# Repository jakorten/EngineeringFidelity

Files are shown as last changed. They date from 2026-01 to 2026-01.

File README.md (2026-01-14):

# Engineering Fidelity of CPR Training Manikins

A research paper for **Measurement Science and Technology** (IOP Publishing) - Focus Collection on *"Data-Centric Exploration and Explanation of Physical and Engineering Phenomena"*

**Deadline:** March 31, 2026

**Invitation:** Personal recommendation by Guest Editor Rui Yuan (Wuhan University of Science and Technology)

**Collection page:** https://iopscience.iop.org/collections/mst-251119-1003

## Overview

This paper develops a data-driven reference model for CPR training manikin characterization, combining chest compression and ventilation mechanics.

### Core Concept

```
Human Reference Model    →    Manikin Characterization    →    Fidelity Gap Analysis
(from medical literature)      (empirical testing)              (model vs. reality)
```

1. Build a human reference model from medical/clinical literature
2. Systematically test multiple CPR manikins against this reference
3. Quantify the "engineering fidelity gap" for each manikin

## Key Contributions

- First systematic benchmark combining compression AND ventilation fidelity
- Data-driven reference model synthesized from published clinical datasets
- Quantified engineering fidelity index for manikin procurement decisions
- Novel ventilation fidelity analysis (largely unstudied area)

## Engineering Fidelity Index (EFI)

The EFI is a quantified metric to score how well a manikin replicates human biomechanics:

```
EFI = w_c * F_compression + w_v * F_ventilation
```

| Component | Description |
|---|---|
| F_compression | Normalized score for stiffness + damping within human envelope |
| F_ventilation | Normalized score for compliance + resistance within human envelope |
| w_c, w_v | Weighting factors (adjustable based on training priorities) |

**Scoring:**
- **EFI = 1.0** - Perfect match to human reference center
- **EFI = 0.0** - Deviation equals full envelope width

Higher EFI = more physiologically realistic manikin. This provides training centers a single number to compare manikins for procurement decisions.

## Paper Structure

1. **Introduction** - Engineering fidelity concept and research gap
2. **Human Reference Model** - Compression and ventilation mechanics from literature
3. **Uncertainty Envelope** - Acceptable range from human variability
4. **Manikin Characterization Protocol** - Standardized testing methodology
5. **Results** - Fidelity comparison across multiple manikins
6. **Engineering Fidelity Index** - Quantified metric proposal
7. **Discussion & Conclusion**

## Related Work

| Paper | Venue | Relationship |
|---|---|---|
| Sensor validation | IEEE TIM | Methodology foundation |
| TEF RCT | IEEE THMS | Training effectiveness evidence |
| [Perspective paper](https://github.com/jakorten/Proposition.git) | Resuscitation | Conceptual framework |
| **This paper** | MST | Technical methodology + data |

The perspective paper argues *for* engineering fidelity; this paper provides the *tools to measure* it.

## Current Status

| Section | Status |
|---|---|
| 1. Introduction | Draft complete |
| 2. Human Reference Model | Draft complete |
| 3. Uncertainty Envelope | Draft complete |
| 4. Manikin Characterization Protocol | Draft complete |
| 5. Results | Awaiting data collection |
| 6. Engineering Fidelity Index | Draft complete |
| 7. Discussion | Draft complete |
| 8. Conclusion | Draft complete |

**Next steps:** Data collection (target: mid-February 2026)

## Repository Structure

```
├── MST_paper_outline.md          # Detailed paper outline
├── MST_paper_supervisor_summary.md  # Executive summary for supervisors
├── CLAUDE.md                     # AI assistant guidance
└── working/
    ├── paper_draft.md            # Current paper draft (~4,750 words)
    ├── literature_review.md      # Comprehensive literature synthesis
    ├── apparatus_expansion.md    # Hardware requirements for manikin testing
    ├── data_collection_checklist.md  # Testing protocol checklist
    ├── articles/                 # Converted reference papers (markdown)
    ├── datasheets/               # Bronkhorst MFM documentation
    │   ├── 6264-ff-m11-en-datasheet.md
    │   ├── 917158-manual-flexi-flow-compact.md
    │   └── N0551_N2510646_A_m.md
    └── scripts/
        └── ventilation_mechanics.py  # C/R calculation module
```

## Key References

### Compression Mechanics
- Tomlinson AE et al. (2007). *Resuscitation*. 72(3):364-370.
- Ruiz de Gauna S et al. (2023). *Comput Methods Programs Biomed*. 242:107847.
- Lim H et al. (2024). *IEEE J Transl Eng Health Med*. 12:542-549.

### Ventilation Mechanics
- Huang J et al. (2016). *J Thorac Dis*. 8(3):513-519.
- Battisti O et al. (2012). *Pediatr Therapeut*. 2(2):114.

## Author

Jan Korten

## License

All rights reserved. Academic research in progress.

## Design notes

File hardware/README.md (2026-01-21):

# Hardware Components

## Compression Actuator Extension

**File:** `Compression Actuator extension.stl`

**Purpose:** Extension piece mounted on load cell for chest compression testing

**Dimensions:**
| Parameter | Value |
|---|---|
| Contact diameter | ~20 mm |
| Extension height | ~23.3 mm |
| Contact shape | Flat/disc |

**Rationale:**

The 20mm contact diameter matches the **overlapping thumbs technique** recommended in current guidelines:

> *"Use the two-thumb-hands-encircling-technique with overlapping or adjacent thumbs to deliver chest compressions."*
> — ERC Guidelines 2025, Newborn Resuscitation

| Thumb Position | Contact Width | Our Actuator |
|---|---|---|
| Adjacent thumbs | ~30-40 mm | - |
| **Overlapping thumbs** | **~15-20 mm** | **~20 mm ✓** |

**Guidelines references:**
- ERC 2025: Two-thumb-hands-encircling with overlapping or adjacent thumbs
- Lim JS et al.: Comparison of overlapping (OP) and adjacent thumb positions (AP)
- Schmölzer 2023: Mechanical CC device with similar contact design

**Conclusion:** The 20mm actuator is appropriate for characterizing manikin response to the **overlapping thumbs technique** per ERC 2025 guidelines.

**Mounting:**
- Attaches to DYMH-103 load cell
- Load cell mounted on CNC linear actuator (BlackBox X32)

---

## Load Cell

**Model:** DYMH-103
**Range:** 0-5 kg (0-49 N)
**Application:** Infant compression (target force ~14-30 N)

**ADC:** HX711 (Sparkfun, 24-bit)
**MCU:** STM32F405

---

## Reference: Schmölzer 2023 Setup

From O'Reilly/Schmölzer (Pediatric Research, 2024):
- Mechanical CC device with flat contact point
- Target depth: 33% AP chest diameter
- CC rate: 90/min
- Acceleration: 500 cm/s²
- Recoil speed: 50 cm/s

Our actuator design is compatible with this approach.

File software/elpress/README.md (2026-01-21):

# EL-PRESS Pressure Sensor

Bronkhorst EL-PRESS P-502C for airway pressure measurement during manikin ventilation characterization.

## Hardware

| Parameter | Value |
|---|---|
| Model | EL-PRESS P-502C |
| Type | Gauge pressure (relative to atmosphere) |
| Range | 0-100 mbar |
| Interface | RS232 via USB adapter |
| Protocol | PROPAR |

## Connection

| Parameter | Value |
|---|---|
| Port | `/dev/cu.usbserial-AQ00Z5CQ` |
| Node address | 4 |
| Baud rate | 38400 |

## Usage

### Setup
```bash
cd software/elpress
source venv/bin/activate
```

### Read pressure
```bash
# Single reading
python read_elpress.py

# Continuous reading (10 seconds, 100ms interval)
python read_elpress.py -c 10 -i 0.1

# Scan for sensor on different nodes
python read_elpress.py --scan
```

### Tare (zero) the sensor
```bash
# Show current offset
python tare_elpress.py

# Set new tare offset
python tare_elpress.py --tare
```

### Diagnostics
```bash
python diagnose_elpress.py
```

## Calibration Notes

- **Warm-up time:** 30 minutes recommended before measurements
- **Baseline offset:** ~45 mbar observed at rest (use tare to zero)
- **Drift:** ~2 mbar/min during warm-up, stabilizes after warm-up
- **Tare procedure:** Run `tare_elpress.py --tare` after warm-up

## PROPAR Parameters

### Measurement Values

| Param | Name | Example | Description |
|---|---|---|---|
| 8 | fmeasure | 23 | Gauge pressure (mbar) - same as `measure` |
| 153 | delta-p | 1.013 | Atmospheric reference (bar) |
| 250 | (absolute?) | 1006.6 | Possibly absolute pressure (mbar) |

### Device Information

| Param | Name | Example | Description |
|---|---|---|---|
| 1 | serial | SNM15211829B | Serial number string |
| 90 | type | DEPC | Device type (Digital Electronic Pressure Controller) |
| 91 | model | P-502C-350R-RGD-33-V | Full model number |
| 92 | serial_alt | M15211829B | Alternative serial |
| 94 | cal_date | 25,11,2015 | Calibration date |
| 105 | firmware | V1.21d | Firmware version |
| 129 | unit | mbar(g) | Measurement unit |
| 175 | ident | 9 | Device identification (9 = DEPC) |

### Configuration

| Param | Name | Example | Description |
|---|---|---|---|
| 21 | capacity | 200.0 | Capacity setting |
| 25 | fluid | AiR | Configured fluid/gas |
| 139 | full_scale | 100.0 | Full scale range (mbar) |
| 167 | capacity_100 | 100.0 | 100% capacity value |
| 246 | baro_press | 1.013 | Barometer pressure (bar) |

### Setpoint (Controller Mode)

| Param | Name | Example | Description |
|---|---|---|---|
| 9 | fsetpoint | 0 | Flow/pressure setpoint |
| setpoint | - | 0 | Setpoint attribute |

## Files

| File | Purpose |
|---|---|
| `read_elpress.py` | Main reader script |
| `tare_elpress.py` | Tare/zero utility |
| `diagnose_elpress.py` | Diagnostic script |
| `elpress_offset.json` | Stored tare offset (auto-generated) |
| `venv/` | Python virtual environment |
| `propar/` | Local propar library |
| `testing_debug/` | Previous debug scripts (FLEXI-FLOW) |

## Dependencies

```bash
pip install propar pyserial
```

Or use the included venv:
```bash
source venv/bin/activate
```

---

## Sensor Specifications (from device)

| Parameter | Value |
|---|---|
| Model | P-502C-350R-RGD-33-V |
| Type | DEPC (Digital Electronic Pressure Controller) |
| Range | 0-100 mbar (gauge) |
| Unit | mbar(g) |
| Fluid | Air |
| Firmware | V1.21d |
| Factory calibration | 25 Nov 2015 |

## Troubleshooting

### Serial errors (Bad file descriptor)
- USB cable may have disconnected
- Another process may be using the port
- Solution: Reconnect USB, restart script

### No response on any node
- Check power (24V required)
- Check RS232 adapter connection
- Try different baud rates (default 38400)

### Readings drift
- Allow 30 min warm-up
- Re-tare after warm-up
- Check for temperature changes

---

*Last updated: 2026-01-21*

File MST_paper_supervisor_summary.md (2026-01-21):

# MST Paper - Supervisor Summary

**Updated:** January 15, 2026

---

## Paper Overview

**Title:** "Mechanical Fidelity of CPR Training Manikins: A Data-Driven Reference Model for Chest Compression and Ventilation Mechanics"

**Key framing:** Traditional "high-fidelity" = visual realism (looks like an infant). Our approach = mechanical fidelity (responds like an infant). *A manikin may look like an infant without responding like one.*

**Target:** Measurement Science and Technology - Special Issue on *"Data-Centric Exploration and Explanation of Physical and Engineering Phenomena"*

**Deadline:** March 31, 2026 (~2.5 months remaining)

**Link:** https://iopscience.iop.org/collections/mst-251119-1003

---

## Current Progress

### Literature Verification: 69% P0 Complete

| Priority | Verified | Total | Coverage |
|---|---|---|---|
| P0 (Critical) | 9 | 13 | **69%** |
| P1 (Important) | 1 | 7 | 14% |
| P2 (Supporting) | 0 | 1 | 0% |
| **Total** | **10** | **21** | **48%** |

**Note:** Remaining P0 claims require our own experimental data (M1, M2, RC1-RC2, RV1-RV3).

### Verified Human Reference Sources

| Domain | Source | Key Data |
|---|---|---|
| **Adult compression** | Nysæther 2008 (n=59 OHCA) | Stiffness ~3-11 N/mm, damping 0.17 N·s/mm |
| **Non-linearity** | Tomlinson 2007 (n=91) | Progressivity factor 1.41±0.25 |
| **Dynamic softening** | Ruiz de Gauna 2023 (n=615) | 34.6% stiffness decrease after 3000 compressions |
| **Infant ventilation** | Huang 2016 (n=205) | Compliance 78-171 mL/kPa, resistance 3.7-6.4 kPa/L/s |
| **Adult ventilation** | Morin 2024 / Charbonney 2018 | Compliance 37-40 mL/cmH₂O, resistance 20 cmH₂O·s/L |

### Confirmed Novelty Claims

- **I2:** No systematic benchmark exists for manikin mechanical properties (only Baubin 1995, 30y old)
- **I3:** First data-driven reference model combining compressions AND ventilations
- **D1:** First systematic multi-manikin benchmark against human reference
- **D2:** Ventilation fidelity is novel contribution (Reiss 2015 called for it, none exists)

---

## Apparatus Status

### Compression Testing
| Component | Status |
|---|---|
| CNC actuator (BlackBox X32) | Operational |
| ToF displacement sensor | Operational, calibrated |
| Load cell | **Installed, needs firmware integration** |

### Ventilation Testing
| Component | Status |
|---|---|
| SDP810 + orifice (flow) | Operational |
| Bronkhorst MFM (reference) | Operational, SI-traceable |
| Airway pressure sensor | **Need MPXV5010DP (~€10)** |

**Gap:** Current sensors insufficient for airway pressure measurement (need 0-20 cmH₂O range for infant manikins).

---

## Remaining Work

### Phase 1: Apparatus (1-2 weeks)
- [ ] Load cell firmware integration + calibration
- [ ] Order and integrate MPXV5010DP pressure sensor
- [ ] System verification with one manikin

### Phase 2: Data Collection (2-3 weeks)
- [ ] Compression characterization (adult + infant manikins)
- [ ] Ventilation characterization (infant manikins)
- [ ] Unit-to-unit variation testing

### Phase 3: Analysis & Writing (3-4 weeks)
- [ ] Reference model fitting with uncertainty envelope
- [ ] Mechanical fidelity index calculation
- [ ] Draft all sections
- [ ] Co-author review and revision

---

## Key Decisions Pending

### DR-001: Reference Model Scope
**Options:**
- A: Adults + infants, compressions + ventilations (full scope)
- B: Focus on infants only (unique data)
- C: Focus on ventilations only (biggest literature gap)

**Recommendation:** Option A if timeline permits; Option C as fallback (strongest novelty).

### DR-002: Manikin Selection
- Which models to include?
- How many replicates per model?
- Dependent on availability assessment

---

## Risk Assessment

| Risk | Likelihood | Mitigation |
|---|---|---|
| Tight timeline (2.5 months) | Medium | Leverage TIM methodology, narrow scope if needed |
| Equipment delays | Low | MPXV5010DP widely available (~€10) |
| Manikin access | Low | Multiple models already available |
| Co-author availability | Medium | Early draft circulation |

---

## Fit with Publication Strategy

```
IEEE TIM (under review)     → Sensor validation methodology
IEEE THMS (under review)    → Training effectiveness (RCT)
Resuscitation (in prep)     → Conceptual framework (perspective)
MST (in progress)           → Technical benchmark methodology  ← THIS PAPER
```

The perspective paper argues *for* mechanical fidelity assessment; **this MST paper provides the tools to measure it.**

---

## Unique Contribution

This paper fills a critical gap: while compression mechanics have some prior characterization (Baubin 1995, Nysæther 2008), **no systematic benchmark exists that:**
1. Tests multiple commercial manikins against human reference data
2. Includes ventilation mechanics (compliance, resistance)
3. Provides a quantitative mechanical fidelity index for procurement decisions

**Key distinction:** We assess how manikins *respond* mechanically (stiffness, compliance, damping), not how they *look*. This "mechanical fidelity" contrasts with traditional "high-fidelity" based on visual realism.

The ventilation fidelity angle is particularly novel—Reiss 2015 explicitly called for manikin compliance/resistance characterization, but no such work has been published.

---

## Next Steps

1. **Immediate:** Order MPXV5010DP, complete load cell integration
2. **This week:** Finalize manikin test matrix, begin compression testing
3. **Decision needed:** Scope confirmation (DR-001)

---

*Summary generated: 2026-01-15*

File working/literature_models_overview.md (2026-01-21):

# Literature Overview: Mechanical Models for Engineering Fidelity

**Purpose:** Template models from literature to adapt for infant manikin fidelity assessment
**Created:** 2026-01-18
**Status:** Work in progress

---

## Conceptual Framework

For each domain (ventilation, compression), we need two types of literature:

| Type | Purpose | Example |
|---|---|---|
| **MODEL** | Mathematical template describing system behavior | Van Meurs, Gruben |
| **REFERENCE** | Biological target values to compare against | Huang 2016, Lamb data |

```
MODEL (equations)  +  REFERENCE (target values)  →  FIDELITY ENVELOPE  →  TEST MANIKINS
```

---

## Summary Table

| Domain | MODEL Source | REFERENCE Source | Status |
|---|---|---|---|
| **Ventilation** | Van Meurs Ch.9, Hyatt Ch.7 | Huang 2016 (infant, n=205) | ✓ Complete |
| **Compression** | Gruben/Thielen, Lim 2024 | Lamb ~3.5kg (Arjen ten Pas) | Lamb data pending |

**Key insight:** Both domains follow the same equation of motion structure:
- **Ventilation:** P = V/C + R×V̇ (elastic + resistive)
- **Compression:** F = k×d + c×ḋ (elastic + damping)

---

## EQUATION SUMMARY (Quick Reference)

### Ventilation

| Equation | Form | Description |
|---|---|---|
| **Equation of motion** | `P = V/C + R×V̇` | Pressure from elastic + resistive terms |
| Compliance definition | `C = ΔV/ΔP` | Volume change per pressure change |
| Resistance definition | `R = ΔP/V̇` | Pressure drop per flow |
| Series compliance | `1/C_total = 1/C_L + 1/C_cw` | Lung + chest wall in series |

| Symbol | Parameter | Unit | Infant Reference |
|---|---|---|---|
| P | Airway pressure | cmH₂O | - |
| V | Volume | mL | Vt = 24.5 mL |
| V̇ | Flow | mL/s or L/s | - |
| C | Compliance | mL/cmH₂O | 7.8 ± 4.6 |
| R | Resistance | cmH₂O·s/L | ~55 |

### Compression

| Equation | Form | Description |
|---|---|---|
| **Equation of motion** | `F = k×d + c×ḋ` | Force from elastic + damping terms |
| **With non-linearity** | `F = k₁d + k₂d² + k₃d³ + k₄d⁴ + d₀ḋ + d₁d·ḋ` | Full Gruben polynomial |
| Stiffness definition | `k = ΔF/Δd` | Force change per displacement |
| Damping definition | `c = ΔF/ḋ` | Force per velocity |

| Symbol | Parameter | Unit | Infant Reference |
|---|---|---|---|
| F | Force | N | - |
| d | Displacement | mm | Target: 27 mm |
| ḋ | Velocity | mm/s | - |
| k | Stiffness | N/mm | Pending (lamb) |
| c | Damping | N·s/mm | Pending (lamb) |

### Structural Parallel

| | Ventilation | Compression |
|--|---|---|
| **Equation** | P = V/C + R×V̇ | F = k×d + c×ḋ |
| **Driving variable** | Pressure P | Force F |
| **State variable** | Volume V | Displacement d |
| **Rate variable** | Flow V̇ | Velocity ḋ |
| **Elastic parameter** | Compliance C | Stiffness k |
| **Resistive parameter** | Resistance R | Damping c |
| **Loop slope** | 1/C | k |
| **Loop width** | 2×R×V̇_max | 2×c×ḋ_max |
| **Loop area** | Work (resistance) | Energy (hysteresis) |

---

## VENTILATION

### Models

#### Van Meurs - Basic Lung Mechanics Model

**Source:** van Meurs WL. *Modeling and Simulation in Biomedical Engineering*. McGraw-Hill. Chapter 9.

**Model Structure:**
```
                    ┌─────────┐
    Pmus(t) ───────►│  Basic  │───► V(t), f(t), Pth(t)
                    │  Lung   │
                    │Mechanics│
                    └─────────┘
```

**Component Diagram:**
- Airway resistance R in series with parallel compliances
- Lung compliance C_L
- Chest wall compliance C_cw
- Muscle pressure generator Pmus(t)

**Mathematical Model:**

State equation (alveolar volume):
```
dV_a(t)/dt = -(C_L + C_cw)/(C_L × C_cw × R) × [V_a(t) - FRC] + (1/R) × Pmus(t)
```

Flow rate:
```
f_a(t) = -(C_L + C_cw)/(C_L × C_cw × R) × [V_a(t) - FRC] + (1/R) × Pmus(t)
```

Intrathoracic pressure:
```
P_th(t) = [V_a(t) - FRC]/C_cw - Pmus(t)
```

**Key Parameters:**
| Parameter | Symbol | Unit | Description |
|---|---|---|---|
| Lung compliance | C_L | mL/cmH₂O | Lung tissue elasticity |
| Chest wall compliance | C_cw | mL/cmH₂O | Chest wall elasticity |
| Airway resistance | R | cmH₂O·s/mL | Flow resistance |
| Functional residual capacity | FRC | mL | End-expiratory volume |

**Relevance for Manikins:**
- Single-compartment model suitable for manikin representation
- Parameters C and R directly measurable
- Simplification: manikin has no muscle pressure → passive inflation only

---

#### Hyatt - Resistance and Compliance Definitions

**Source:** Scanlon PD, Hyatt RE. *Hyatt's Interpretation of Pulmonary Function Tests*. 5th ed. Wolters Kluwer, 2019. Chapter 7.

**Resistance Definition:**
```
R = ΔP / V̇
```
- Units: cmH₂O/L/s (or cmH₂O·s/L)
- Rpulm = (Ppl - Pao) / V̇  (includes tissue resistance)
- Raw = (Palv - Pao) / V̇   (airway resistance only)
- Normal adults: 1-3 cmH₂O/L/s
- **Key insight:** Resistance varies inversely with lung volume

**Compliance Definition:**
```
CL = ΔV / ΔP
```
- Units: L/cmH₂O (or mL/cmH₂O)
- Static compliance (CLstat): measured at zero flow
- Dynamic compliance (CLdyn): measured during breathing
- Normal adults: 0.150-0.250 L/cmH₂O (150-250 mL/cmH₂O)
- **Key insight:** Compliance varies directly with lung size

**Respiratory System Compliance (series combination):**
```
1/Crs = 1/CL + 1/Ccw
```
Or using elastance (E = 1/C):
```
Ers = EL + Ecw
```

**Clinical Ranges (Adult):**
| Condition | CLstat | Notes |
|---|---|---|
| Normal | 150-250 mL/cmH₂O | Varies with size |
| Fibrosis | ~50 mL/cmH₂O | Stiff lungs |
| Emphysema | >500 mL/cmH₂O | Floppy lungs |

---

#### P-V Relationship (Equation of Motion)

**The fundamental equation for respiratory mechanics:**
```
P = V/C + R × V̇
```
Where:
- P = Airway pressure (cmH₂O)
- V = Volume above FRC (mL)
- C = Compliance (mL/cmH₂O)
- R = Resistance (cmH₂O·s/mL or cmH₂O/L/s)
- V̇ = Flow rate (mL/s or L/s)

**This creates a P-V loop because:**
- During **inspiration**: V̇ > 0 → P = V/C + R×(+flow) → higher pressure
- During **expiration**: V̇ < 0 → P = V/C + R×(-flow) → lower pressure

**Loop characteristics:**
| Feature | Determined by |
|---|---|
| Slope of loop | 1/C (compliance) |
| Width of loop | 2 × R × V̇_max (resistance) |
| Loop area | Energy dissipated (work against resistance) |

**Structural parallel with compression:**
| Domain | Elastic term | Resistive term | Equation |
|---|---|---|---|
| Ventilation | V/C | R × V̇ | P = V/C + R×V̇ |
| Compression | k × d | c × ḋ | F = k×d + c×ḋ |

This parallel means the same analysis approach applies to both domains.

---

### Reference Data

#### Battisti 2012 - Neonatal Values

**Source:** Battisti O et al. *Lung Compliance and Airways Resistance in Healthy Neonates*. Pediatr Therapeut 2012.

**Data (healthy neonates, n=32):**

| Parameter | Day 1 | Day 3 | Day 7 | Day 14 | Day 21 |
|---|---|---|---|---|---|
| Crs (mL/cmH₂O) | 1.37±0.37 | 1.60±0.40 | 1.67±0.41 | 1.62±0.44 | 1.56±0.42 |

**Key Findings:**
- 20% increase in Crs after birth
- Females had significantly higher Crs values
- RDS reduces Crs ~4× in acute phase

#### Huang 2016 - Infant Reference Values (PRIMARY)

**Source:** Huang J et al. *Reference values for resistance and compliance in healthy infants*. J Thorac Dis 2016; 8(3):513-519.

**Reference Data (n=205):**

| Age Range | Compliance | Resistance |
|---|---|---|
| 1-24 weeks | ~78 mL/kPa (7.8 mL/cmH₂O) | ~6.4 kPa/L/s |
| 73-96 weeks | ~171 mL/kPa | ~3.7 kPa/L/s |

**Target for 3.5 kg infant manikin:**
| Parameter | Symbol | Value | Unit |
|---|---|---|---|
| Compliance | C | 7.8 ± 4.6 | mL/cmH₂O |
| Resistance | R | ~55 | cmH₂O·s/L |
| Tidal volume | Vt | 24.5 | mL (7 mL/kg) |

---

## COMPRESSION

### Models

#### Gruben/Thielen - Force-Displacement Model

**Sources:**
- Gruben KG et al. IEEE Trans Biomed Eng 1990, 1999
- Thielen M et al. Proc IMechE Part H 2017

**Model Equation:**
```
F = F_e + F_d
```

Where:
- **Elastic component:** `F_e = k(z) × z`
- **Damping component:** `F_d = μ(z) × ż`

**Nonlinear stiffness:**
```
k(z) = k₁ + k₂·z + k₃·z² + k₄·z³
```

**Displacement-dependent damping:**
```
μ(z) = d₀ + d₁·z
```

**Full polynomial form:**
```
F = k₁·z + k₂·z² + k₃·z³ + k₄·z⁴ + d₀·ż + d₁·z·ż
```

**Key Parameters:**
| Parameter | Symbol | Unit | Description |
|---|---|---|---|
| Linear stiffness | k₁ | N/mm | Initial slope |
| Quadratic stiffness | k₂ | N/mm² | Non-linearity |
| Cubic stiffness | k₃ | N/mm³ | Progressive stiffening |
| Quartic stiffness | k₄ | N/mm⁴ | Higher-order term |
| Initial damping | d₀ | N·s/mm | Velocity-dependent loss |
| Depth-dependent damping | d₁ | N·s/mm² | Depth-velocity interaction |

**Thielen 2017 Key Finding:**
- Novel manikin shows nonlinear behavior (k₂, k₃, k₄ non-zero)
- Classical manikins: only k₂ non-zero (nearly linear)
- Human chest: all higher-order terms present

---

#### Lim 2024 - Equation of Motion

**Source:** Lim H et al. *Variable Stiffness and Damping Mechanism for CPR Manikin*. IEEE JTEHM 2024.

**Equation of motion:**
```
F_ext = k×d + c×ḋ
```

Where:
- F_ext = External force (N)
- d = Displacement (mm)
- k = Stiffness (N/mm)
- c = Damping coefficient (N·s/mm)
- ḋ = Velocity (mm/s)

**System ranges achieved:**
| Parameter | Range | Human chest range |
|---|---|---|
| Stiffness | 5.34-13.59 N/mm | 4-10 N/mm (at 50mm) |
| Damping | 0.127-0.511 N·s/mm | 0.08-0.38 N·s/mm |

**Key insight:** Both stiffness AND damping must be controllable to simulate human chest variation.

---

### Reference Data

#### Adult Compression (for context, not our target)

**Sources:** Lim 2024, Tomlinson 2007, Ruiz de Gauna 2023, Neurauter 2009

| Property | Value | Source |
|---|---|---|
| Stiffness at 50mm | 4-10 N/mm | Lim 2024 |
| Damping at 30mm | 0.08-0.38 N·s/mm | Lim 2024 |
| Force for 38mm | 27.5±13.6 kg | Tomlinson 2007 |
| Dynamic softening | -34.6% over 3000 compressions | Ruiz de Gauna 2023 |

**Key Quotes:**
> "Commonly used CPR training manikins...usually have spring loaded chests with a **linear relationship between force and depth**." - Tomlinson 2007

> "Mechanical properties of commercially available CPR training manikins remain constant and **no information on these properties is provided by the manufacturers**." - Lim 2024

#### Infant Compression Reference - PENDING

**Status:** No human infant data exists (ethical constraints)

**Surrogate Reference:** Lamb data (~3.5 kg) from Arjen ten Pas (LUMC) - pending DR-003

---

#### Animal Models in Neonatal Resuscitation Research

| Aspect | Piglet | Lamb |
|---|---|---|
| **Primary use** | Chest compression mechanics | Ventilation/fetal transition |
| **Chest mechanics** | Similar to infant | Different geometry |
| **Circulation model** | Postnatal | Fetal → neonatal |
| **Lung state** | Air-filled | Fluid → air transition |
| **Weight** | 1.7-2.4 kg | ~3.5 kg |

**Piglet model:**
- Chest geometry similar to human infant (broader chest)
- Similar chest size and stiffness
- Stiffness: 4.8 N/mm initially, 2.9 N/mm after 200 compressions (Neurauter 2009)
- Well-established for CPR research

**Key piglet reference - Schmölzer 2023:**
- O'Reilly M, Schmölzer GM et al. (2023). *Comparison of hemodynamic effects of chest compression delivered via machine or human in asphyxiated piglets*. Pediatric Research.
- Weight: 2.12 ± 0.17 kg (matches term infant)
- Age: 0-3 days (neonatal)
- Force recorded during mechanical compressions
- **Potential data source:** Force-displacement data for stiffness calculation
- Contact: georg.schmoelzer@me.com (email draft ready)

**Lamb model:**
- Ideal for fetal-to-neonatal transition studies
- Used for ventilation/oxygenation research (fluid-filled → air-filled lungs)
- Larger size allows instrumentation
- Different chest geometry than piglets

**Note:** Piglet data may be more directly relevant for compression mechanics, but lamb data is what's potentially available via LUMC collaboration. Worth confirming with Arjen ten Pas what parameters are typically measured on lambs.

**Required Parameters (same as model):**
| Parameter | Symbol | Unit | Status |
|---|---|---|---|
| Stiffness | k | N/mm | Pending |
| Non-linearity | k_nl | N/mm² | Pending |
| Damping | μ | N·s/mm | Pending |
| Sample size | n | - | Pending |
| Weight range | - | kg | Pending |

---

## MODEL ADAPTATION FOR INFANT MANIKINS

### Ventilation Model (Simplified for Passive Manikin)

Since manikins have no muscle pressure generator, the model simplifies to:

**Pressure-Volume relationship:**
```
P_aw = V/C + R × dV/dt
```

Where:
- P_aw = Airway pressure (cmH₂O)
- V = Volume (mL)
- C = Total compliance (mL/cmH₂O)
- R = Airway resistance (cmH₂O·s/mL)
- dV/dt = Flow (mL/s)

**P-V Loop:**
- Inflation limb: P = V/C + R×flow (positive flow)
- Deflation limb: P = V/C - R×|flow| (negative flow)
- Loop width proportional to R
- Slope proportional to 1/C

**Target Envelope (Huang 2016):**
- C = 7.8 ± 4.6 mL/cmH₂O
- For Vt = 24.5 mL: P_peak = 2-8 cmH₂O

---

### Compression Model (Simplified for Manikins)

**Quasi-static (low rate):**
```
F = k × d + k_nl × d²
```

**With damping (at CPR rates):**
```
F = k × d + k_nl × d² + μ × ḋ
```

Where:
- k = Linear stiffness (N/mm)
- k_nl = Non-linearity coefficient
- μ = Damping coefficient (N·s/mm)
- d = Displacement (mm)
- ḋ = Velocity (mm/s)

**Hysteresis Loop:**
- Compression limb: F = f(d, +ḋ)
- Release limb: F = f(d, -ḋ) × (1 - damping_fraction)
- Loop area = Energy dissipated

---

## GAPS AND NEXT STEPS

### Literature Status

| Item | Status | Notes |
|---|---|---|
| Ventilation model | ✓ Complete | Van Meurs, Hyatt |
| Ventilation reference | ✓ Complete | Huang 2016 (infant) |
| Compression model | ✓ Complete | Gruben/Thielen, Lim 2024 |
| Compression reference | **PENDING** | Lamb data from Arjen ten Pas (DR-003) |

### Remaining Gaps

| Gap | Status | Action |
|-----|---|---|
| Infant compression reference | Pending | Await lamb data from LUMC |
| Manikin characterization data | Our contribution | Experimental work |

### Next Steps

1. [x] ~~Add Hyatt reference for ventilation~~ - Done
2. [ ] Obtain lamb data from Arjen ten Pas (LUMC) - DR-003 in progress
3. [ ] Define infant-specific parameter ranges for compression
4. [ ] Create reference envelope plots with uncertainty bands
5. [ ] Design experimental protocol to measure manikin parameters

---

## References

### Ventilation Models
1. van Meurs WL. *Modeling and Simulation in Biomedical Engineering: Applications in Cardiorespiratory Physiology*. McGraw-Hill. Chapter 9.
2. Scanlon PD, Hyatt RE. *Hyatt's Interpretation of Pulmonary Function Tests*. 5th ed. Wolters Kluwer, 2019. Chapter 7.

### Ventilation Reference Data
3. Huang J et al. (2016). Reference values for resistance and compliance in healthy infants. J Thorac Dis 8(3):513-519.
4. Battisti O et al. (2012). Lung Compliance and Airways Resistance in Healthy Neonates. Pediatr Therapeut 2:114.

### Compression Models
5. Gruben KG et al. (1990). Identification of dynamic mechanical parameters of the human chest. IEEE Trans Biomed Eng 37(2):211-217.
6. Thielen M et al. (2017). An innovative design for cardiopulmonary resuscitation manikins. Proc IMechE Part H. DOI: 10.1177/0954411917691555
7. Lim H et al. (2024). Variable Stiffness and Damping Mechanism for CPR Manikin. IEEE JTEHM. DOI: 10.1109/JTEHM.2024.3429422

### Compression Reference Data (Adult)
8. Tomlinson AE et al. (2007). Compression force-depth relationship during out-of-hospital CPR. Resuscitation 72:364-370.
9. Ruiz de Gauna S et al. (2023). Characterization of mechanical properties of adult chests. Comput Methods Programs Biomed 242:107847.
10. Neurauter A et al. (2009). Comparison of mechanical characteristics of the human and porcine chest. Resuscitation.

### Compression Reference Data (Infant/Neonatal Animal Surrogate)
11. O'Reilly M, Schmölzer GM et al. (2023). Comparison of hemodynamic effects of chest compression delivered via machine or human in asphyxiated piglets. *Pediatric Research*. doi:10.1038/s41390-023-2827-1
12. Lamb data from Arjen ten Pas (LUMC) - awaiting DR-003

---

*Document to be updated as literature review progresses*

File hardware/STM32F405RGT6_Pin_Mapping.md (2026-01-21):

# STM32F405RGT6 Pin Mapping

## Power Pins

| Pin | MCU Pin | Signal/Connection |
|-----|---|---|
| 1 | VBAT | 3.3V |
| 19 | VDD1 | 3.3V |
| 32 | VDD2 | 3.3V |
| 48 | VDD3 | 3.3V |
| 64 | VDD4 | 3.3V |
| 13 | VDDA | 3.3V |
| 31 | VCAP1 | 2.2µF to GND (C5) |
| 47 | VCAP2 | 2.2µF to GND (C6) |
| 18 | VSS1 | GND |
| 63 | VSS2 | GND |
| 12 | VSSA | GND |

## System Pins

| Pin | MCU Pin | Signal/Connection |
|-----|---|---|
| 7 | NRST | RESET |
| 60 | BOOT0 | BOOT0 |

## Crystal Oscillators

| Pin | MCU Pin | Signal/Connection |
|-----|---|---|
| 5 | PH0 | Y1 (12MHz HSE) + 22pF (C1) |
| 6 | PH1 | Y1 (12MHz HSE) + 22pF (C2) |
| 3 | PC14 | Y2 (32.768kHz LSE) + 15pF (C3) |
| 4 | PC15 | Y2 (32.768kHz LSE) + 15pF (C4) |

## Port A

| Pin | MCU Pin | Signal/Connection |
|-----|---|---|
| 14 | PA0 | G2 |
| 15 | PA1 | BATT_VIN |
| 16 | PA2/UART2_TX | TX1 |
| 17 | PA3/UART2_RX | RX1 |
| 20 | PA4/SPI1_NSS | AUD_LRCLK |
| 21 | PA5/SPI1_SCK | SCK |
| 22 | PA6/SPI1_MISO | CIPO |
| 23 | PA7/SPI1_MOSI | COPI |
| 41 | PA8 | G1 |
| 42 | PA9/UART1_TX | — |
| 43 | PA10/UART1_RX | — |
| 44 | PA11 | D- (via 22Ω R2) |
| 45 | PA12 | D+ (via 22Ω R3) |
| 46 | PA13/JTMS | SWDIO |
| 49 | PA14/JTCK | SWCLK |
| 50 | PA15/JTDI | STAT |

## Port B

| Pin | MCU Pin | Signal/Connection |
|-----|---|---|
| 26 | PB0 | A1 |
| 27 | PB1 | INT |
| 28 | PB2-BOOT1 | — |
| 55 | PB3/JTDO | AUD_BCLK |
| 56 | PB4/JTRST | AUD_OUT |
| 57 | PB5 | AUD_IN |
| 58 | PB6 | SCL1 |
| 59 | PB7 | SDA1 |
| 61 | PB8 | CAN_RX |
| 62 | PB9 | CAN_TX |
| 29 | PB10 | SCL |
| 30 | PB11 | SDA |
| 33 | PB12/I2S2_WS | HOST_ID |
| 34 | PB13/I2S2_CK | HOST_VBUS |
| 35 | PB14/I2S2_XD | HOST_D- |
| 36 | PB15/I2S2_SD | HOST_D+ |

## Port C

| Pin | MCU Pin | Signal/Connection |
|-----|---|---|
| 8 | PC0 | D0 |
| 9 | PC1 | D1 |
| 10 | PC2 | G6 |
| 11 | PC3 | FLASH_CS |
| 24 | PC4 | CS |
| 25 | PC5 | A0 |
| 37 | PC6/I2S2_MCK | PWM0 |
| 38 | PC7 | PWM1 |
| 39 | PC8/SDIO_D0 | G3 |
| 40 | PC9/SDIO_D1 | G4 |
| 51 | PC10/SDIO_D2 | FLASH_SCK |
| 52 | PC11/SDIO_D3 | FLASH_SDO |
| 53 | PC12/SDIO_CLK | FLASH_SDI |
| 2 | PC13 | G5 |

## Port D

| Pin | MCU Pin | Signal/Connection |
|-----|---|---|
| 54 | PD2/SDIO_CMD | G0 |

## Functional Summary

| Function | Pins/Signals |
|---|---|
| **USB FS** | PA11 (D-), PA12 (D+) via 22Ω resistors |
| **USB Host** | HOST_ID, HOST_VBUS, HOST_D-, HOST_D+ |
| **SWD** | SWDIO (PA13), SWCLK (PA14) |
| **UART1** | PA9 (TX), PA10 (RX) |
| **UART2** | TX1 (PA2), RX1 (PA3) |
| **SPI1** | SCK (PA5), CIPO (PA6), COPI (PA7), AUD_LRCLK (PA4) |
| **I2C (Bus 0)** | SCL (PB10), SDA (PB11) |
| **I2C (Bus 1)** | SCL1 (PB6), SDA1 (PB7) |
| **CAN** | CAN_RX (PB8), CAN_TX (PB9) |
| **Audio/I2S** | AUD_BCLK, AUD_OUT, AUD_IN, AUD_LRCLK |
| **SPI Flash** | FLASH_CS, FLASH_SCK, FLASH_SDO, FLASH_SDI |
| **PWM** | PWM0 (PC6), PWM1 (PC7) |
| **GPIO** | G0-G6, A0, A1, D0, D1, INT, CS, STAT |

---

## MicroMod Connector (J1) - MICROMOD-2222

### Power & System

| Pin | MicroMod Signal | Board Connection |
|-----|---|---|
| 2*2 | 3.3V | 3.3V |
| 1*10 | GND | GND |
| 4 | 3.3V_EN | — |
| 72 | RTC_3V | — |
| 9 | USB_VIN | — |
| 49 | BATT_VIN/3 | BATT_VIN |

### Reset & Boot

| Pin | MicroMod Signal | Board Connection |
|-----|---|---|
| 6 | RESET | RESET |
| 11 | BOOT | BOOT |

### USB (Device)

| Pin | MicroMod Signal | Board Connection |
|-----|---|---|
| 5 | USB_D- | D- |
| 3 | USB_D+ | D+ |

### USB Host

| Pin | MicroMod Signal | Board Connection |
|-----|---|---|
| 37 | USBHOST_D- | HOST_D- |
| 35 | USBHOST_D+ | HOST_D+ |
| 63 | G10/ADC_D+/CAM_VSYNC | HOST_VBUS |
| 8 | G11 | HOST_ID |

### SWD (Debug)

| Pin | MicroMod Signal | Board Connection |
|-----|---|---|
| 23 | SWDIO | SWDIO |
| 21 | SWDCK | SWCLK |

### CAN Bus

| Pin | MicroMod Signal | Board Connection |
|-----|---|---|
| 43 | CAN-TX | CAN_TX |
| 41 | CAN-RX | CAN_RX |

### SPI (Primary)

| Pin | MicroMod Signal | Board Connection |
|-----|---|---|
| 57 | SPI_SCK | SCK |
| 59 | SPI_SDO | COPI |
| 61 | SPI_SDI | CIPO |
| 55 | SPI_CS | CS |

### SPI1 / SDIO

| Pin | MicroMod Signal | Board Connection |
|-----|---|---|
| 60 | SPI_SCK1/SDIO_CLK | — |
| 62 | SPI_SDO1/SDIO_CMD | — |
| 64 | SPI_SDI1/SDIO_DATA0 | — |
| 66 | SDIO_DATA1 | — |
| 68 | SDIO_DATA2 | — |
| 70 | SPI_CS1/SDIO_DATA3 | — |

### I2C (Primary)

| Pin | MicroMod Signal | Board Connection |
|-----|---|---|
| 14 | I2C_SCL | SCL |
| 12 | I2C_SDA | SDA |
| 16 | I2C_INT | INT |

### I2C (Secondary)

| Pin | MicroMod Signal | Board Connection |
|-----|---|---|
| 53 | I2C_SCL1 | SCL1 |
| 51 | I2C_SDA1 | SDA1 |

### Audio / I2S / Camera

| Pin | MicroMod Signal | Board Connection |
|-----|---|---|
| 58 | AUD_MCLK | — |
| 56 | AUD_OUT/CAM_MCLK | AUD_OUT |
| 54 | AUD_IN/CAM_PCLK | AUD_IN |
| 52 | AUD_LRCLK | AUD_LRCLK |
| 50 | AUD_BCLK | AUD_BCLK |

### UART1

| Pin | MicroMod Signal | Board Connection |
|-----|---|---|
| 17 | TX1 | TX1 |
| 19 | RX1 | RX1 |
| 13 | RTS1 | — |
| 15 | CTS1 | — |

### UART2

| Pin | MicroMod Signal | Board Connection |
|-----|---|---|
| 22 | TX2 | — |
| 20 | RX2 | — |

### Analog

| Pin | MicroMod Signal | Board Connection |
|-----|---|---|
| 34 | A0 | A0 |
| 38 | A1 | A1 |

### PWM

| Pin | MicroMod Signal | Board Connection |
|-----|---|---|
| 32 | PWM0 | PWM0 |
| 47 | PWM1 | PWM1 |

### Digital I/O

| Pin | MicroMod Signal | Board Connection |
|-----|---|---|
| 10 | D0 | D0 |
| 18 | D1/CAM_TRIG | D1 |

### GPIO / BUS

| Pin | MicroMod Signal | Board Connection |
|-----|---|---|
| 40 | G0/BUS0 | G0 |
| 42 | G1/BUS1 | G1 |
| 44 | G2/BUS2 | G2 |
| 46 | G3/BUS3 | G3 |
| 48 | G4/BUS4 | G4 |
| 73 | G5/BUS5 | G5 |
| 71 | G6/BUS6 | G6 |
| 69 | G7/BUS7 | — |
| 67 | G8 | — |
| 65 | G9/ADC_D-/CAM_HSYNC | — |

---

## Cross-Reference: MicroMod ↔ STM32F405

| MicroMod Pin | MicroMod Signal | STM32 Pin | STM32 GPIO |
|---|---|---|---|
| 6 | RESET | 7 | NRST |
| 11 | BOOT | 60 | BOOT0 |
| 5 | USB_D- | 44 | PA11 |
| 3 | USB_D+ | 45 | PA12 |
| 37 | USBHOST_D- | 35 | PB14 |
| 35 | USBHOST_D+ | 36 | PB15 |
| 63 | HOST_VBUS | 34 | PB13 |
| 8 | HOST_ID | 33 | PB12 |
| 23 | SWDIO | 46 | PA13 |
| 21 | SWDCK | 49 | PA14 |
| 43 | CAN-TX | 62 | PB9 |
| 41 | CAN-RX | 61 | PB8 |
| 57 | SPI_SCK | 21 | PA5 |
| 59 | SPI_SDO | 23 | PA7 |
| 61 | SPI_SDI | 22 | PA6 |
| 55 | SPI_CS | 24 | PC4 |
| 14 | I2C_SCL | 29 | PB10 |
| 12 | I2C_SDA | 30 | PB11 |
| 16 | I2C_INT | 27 | PB1 |
| 53 | I2C_SCL1 | 58 | PB6 |
| 51 | I2C_SDA1 | 59 | PB7 |
| 56 | AUD_OUT | 56 | PB4 |
| 54 | AUD_IN | 57 | PB5 |
| 52 | AUD_LRCLK | 20 | PA4 |
| 50 | AUD_BCLK | 55 | PB3 |
| 17 | TX1 | 16 | PA2 |
| 19 | RX1 | 17 | PA3 |
| 34 | A0 | 25 | PC5 |
| 38 | A1 | 26 | PB0 |
| 32 | PWM0 | 37 | PC6 |
| 47 | PWM1 | 38 | PC7 |
| 10 | D0 | 8 | PC0 |
| 18 | D1 | 9 | PC1 |
| 40 | G0 | 54 | PD2 |
| 42 | G1 | 41 | PA8 |
| 44 | G2 | 14 | PA0 |
| 46 | G3 | 39 | PC8 |
| 48 | G4 | 40 | PC9 |
| 73 | G5 | 2 | PC13 |
| 71 | G6 | 10 | PC2 |
| 49 | BATT_VIN | 15 | PA1 |

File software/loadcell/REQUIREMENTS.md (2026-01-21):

# Load Cell Data Acquisition Requirements

## Hardware Configuration

| Component | Specification |
|---|---|
| **Load Cell** | DYMH-103 |
| **Range** | 0-5 kg (0-49 N) |
| **ADC** | HX711 (Sparkfun, 24-bit) |
| **MCU** | STM32F405 |

## Application Context

- **Use case:** Infant chest compression force measurement
- **Target force range:** 14-30 N (infant CPR)
- **Actuator:** 20mm diameter compression extension (see `hardware/`)

---

## Functional Requirements

### FR-01: Force Measurement
- **FR-01.1:** Measure compressive force with resolution ≤ 0.1 N
- **FR-01.2:** Support measurement range 0-49 N (full load cell range)
- **FR-01.3:** Handle both compression (positive) and release (negative/zero) phases

### FR-02: Sampling Rate
- **FR-02.1:** Sample force at ~80 Hz (HX711 hardware limit)
- **FR-02.2:** Timestamp each sample with millisecond resolution

### FR-03: Data Output
- **FR-03.1:** Output timestamped force values via serial (USB or UART)
- **FR-03.2:** Format: CSV-compatible (`timestamp_ms, force_N`)
- **FR-03.3:** Support streaming mode for real-time acquisition

### FR-04: Calibration
- **FR-04.1:** Support zero/tare function
- **FR-04.2:** Support two-point calibration (zero + known weight)
- **FR-04.3:** Calibration stored in RAM (re-calibrate each session)

---

## Non-Functional Requirements

### NFR-01: Accuracy
- **NFR-01.1:** Force measurement accuracy ≤ ±0.5 N within operating range
- **NFR-01.2:** Repeatability ≤ ±0.2 N

### NFR-02: Latency
- **NFR-02.1:** End-to-end latency (force applied → data available) < 20 ms

### NFR-03: Drift
- **NFR-03.1:** Zero drift < 0.1 N over 10-minute measurement session
- **NFR-03.2:** Temperature compensation if drift exceeds spec

---

## Interface Requirements

### IR-01: HX711 ADC Interface
- **IR-01.1:** Configure HX711 for 80 Hz sample rate (RATE pin HIGH)
- **IR-01.2:** Use Channel A, Gain 128 (default for load cells)
- **IR-01.3:** Implement proper timing for DOUT/SCK protocol

### IR-02: Serial Output
- **IR-02.1:** Baud rate: 115200
- **IR-02.2:** Protocol: ASCII, newline-terminated
- **IR-02.3:** Commands: `TARE`, `CAL`, `START`, `STOP`, `READ`, `RAW`, `STATUS`, `HELP`

---

## Test Protocol Integration

| Parameter | Unit | Rate |
|---|---|---|
| Force | N | ~80 Hz (HX711 limit) |
| Timestamp | ms | Per sample |

**Test modes to support:**
1. **Quasi-static:** 2 mm/s compression rate (stiffness measurement)
2. **Dynamic:** 100/min (~1.7 Hz) compression rate (damping measurement)

---

## Implementation Notes

### HX711 Considerations
- HX711 native rate is 10 Hz or 80 Hz (set by RATE pin)
- Current implementation: 80 Hz mode, ~83 Hz polling interval
- Tare/calibration uses 10-sample averaging for noise reduction

### STM32F405 Resources
- Polling-based sampling using `millis()`
- USB CDC for serial output

---

## References

- DYMH-103 load cell datasheet
- HX711 datasheet (Avia Semiconductor)
- Sparkfun HX711 breakout documentation
- STM32F405 reference manual

---

*Created: 2026-01-19*

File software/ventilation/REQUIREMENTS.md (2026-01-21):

# Ventilation Data Acquisition Requirements

## Hardware Configuration

| Component | Specification |
|---|---|
| **Sensor** | Bronkhorst FLEXI-FLOW Compact FF-M11 |
| **Type** | Mass flow and pressure meter |
| **Flow ranges** | 0.5 / 2 / 5 / 20 ln/min (selectable) |
| **Current config** | 2 ln/min (TBC) |
| **Pressure range** | 0-17 bar(a) |

## Sensor Specifications (from datasheet)

| Parameter | Value |
|---|---|
| Accuracy | ±0.5% Rd + ±0.1% FS |
| Repeatability | < ±0.2% Rd |
| Turndown ratio | up to 1:1000 |
| Response time | < 30 ms (T63) |
| Warm-up time | 30 minutes |

## Communication Interfaces

| Interface | Specification |
|---|---|
| Digital | Modbus-RTU, Modbus-ASCII, FLOW-BUS |
| Ethernet | EtherCAT, EtherNet/IP, Modbus-TCP, PROFINET, POWERLINK |
| Service | USB-C, Bluetooth |
| Connector | 9-pin D-sub (RS485) or 2x RJ45 (Ethernet) |

## Power Requirements

| Parameter | Value |
|---|---|
| Supply voltage | +24 Vdc ±10% |
| Power consumption | 0.5 W typical (+0.9 W for Ethernet) |

---

## Application Context

- **Use case:** Infant manikin ventilation characterization
- **Target parameters:** Compliance (mL/kPa), Resistance (kPa/L/s)
- **Reference:** Huang 2016 infant ventilation mechanics

### Infant Ventilation Reference Values

| Parameter | Infant (1-24 wks) | Infant (73-96 wks) |
|---|---|---|
| Compliance | ~80 mL/kPa | ~170 mL/kPa |
| Resistance | ~6 kPa/L/s | ~4 kPa/L/s |

### Typical Test Parameters

| Parameter | Value | Notes |
|---|---|---|
| Tidal volume | 5-7 mL/kg | ~17-25 mL for 3.5 kg infant |
| Ventilation rate | 40-60/min | Neonatal range |
| Peak inspiratory pressure | 20-25 cmH2O | Initial breaths may be higher |

---

## Functional Requirements

### FR-01: Flow Measurement
- **FR-01.1:** Measure inspiratory and expiratory flow
- **FR-01.2:** Calculate tidal volume by flow integration
- **FR-01.3:** Support bidirectional flow (inspiration/expiration)

### FR-02: Pressure Measurement
- **FR-02.1:** Measure airway pressure during ventilation
- **FR-02.2:** Resolution sufficient for infant pressures (0-40 cmH2O)

### FR-03: Sampling Rate
- **FR-03.1:** Sample flow and pressure at minimum 100 Hz
- **FR-03.2:** Timestamp each sample with millisecond resolution

### FR-04: Data Output
- **FR-04.1:** Output timestamped flow and pressure values
- **FR-04.2:** Format: CSV-compatible (`timestamp_ms, flow_ln_min, pressure_mbar`)
- **FR-04.3:** Support streaming mode for real-time acquisition

### FR-05: Derived Parameters
- **FR-05.1:** Calculate tidal volume (integral of flow)
- **FR-05.2:** Calculate compliance (ΔV / ΔP)
- **FR-05.3:** Calculate resistance (ΔP / flow)

---

## Interface Requirements

### IR-01: Communication Protocol
- **IR-01.1:** Use Modbus-RTU or FLOW-BUS for data acquisition
- **IR-01.2:** Alternatively USB-C for direct connection
- **IR-01.3:** Configure via Bronkhorst FlowSuite software

### IR-02: Gas Configuration
- **IR-02.1:** Configure for Air (default) or appropriate test gas
- **IR-02.2:** Embedded gas data available for 22 gases + mixtures

---

## Implementation Notes

### FLEXI-FLOW Considerations
- 30-minute warm-up required for rated accuracy
- Sensor response < 30 ms sufficient for ventilation dynamics
- Built-in pressure correction available

### Integration Options
1. **Direct USB-C:** Simplest, use FlowSuite for configuration and logging
2. **Modbus-RTU:** Via RS485 to MCU for synchronized acquisition
3. **Ethernet:** For networked/remote data collection

---

## References

- Bronkhorst FLEXI-FLOW Compact FF-M11 datasheet (6264-ff-m11-en)
- Bronkhorst FLEXI-FLOW manual (917158)
- Huang J et al. (2016). Reference values for resistance and compliance in healthy infants

---

*Created: 2026-01-20*

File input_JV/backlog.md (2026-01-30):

# Project Backlog

**Paper:** Mechanical Fidelity of CPR Training Manikins
**Target:** MST Special Issue - March 31, 2026

---

## Open Tasks

### Methodology Setup
- [x] Adopt V&V methodology from Proposition (DR-000)
- [x] Create directory structure
- [x] Create claim registry template
- [x] Add AI-assisted review prompts (adapted from TIM review guide)
- [ ] Populate claim registry with initial claims from outline

### Human Reference Model (Literature)
- [x] Extract existing data from Proposition repo
- [x] Obtain PDFs: Lim 2024, Tomlinson 2007, Ruiz de Gauna 2023, Neurauter 2009 (from Proposition)
- [x] Obtain PDFs: Huang 2016, Battisti 2012 (open access downloads)
- [x] Verify stiffness/damping values (C1, C2) — **Nysæther 2008 is primary source for human data; Lim 2024 describes manikin range**
- [x] Verify Tomlinson 2007 non-linearity (C3) — **Confirmed: progressivity factor 1.41±0.25**
- [x] Verify Ruiz de Gauna 2023 dynamic softening (C4) — **Confirmed: 34.6% decrease**
- [x] Verify Huang 2016 infant compliance/resistance (V1, V2) — **Confirmed: 78-171 mL/kPa, 3.7-6.4 kPa/L/s**
- [x] Verify infant compression data gap (C5) — **Confirmed via Babic 2017, Thielen 2017**
- [x] Verify novelty claims (I2, I3, D1, D2) — **No competing work found**
- [x] Found Nysæther 2008 — primary source for human chest properties (n=59)
- [x] Found Morin 2024 — adult ventilation reference values (compliance 37-40 mL/cmH₂O)

### Experimental Planning
- [ ] Define manikin test matrix (which manikins, how many replicates)
- [x] Confirm compression apparatus availability — **DONE: Load cell firmware complete, verified ±0.13 N accuracy**
- [~] Design/source ventilation measurement apparatus — **Need MPXV5010DP (~€10) for airway pressure; SDP810+MFM for flow ready**
- [x] Create experimental protocol document — **DONE: `protocols/ventilation_fidelity_measurement_tutorial.md`**
- [ ] Plan data file naming convention
- [ ] Create BOM (Bill of Materials) for compression apparatus
- [ ] Create BOM (Bill of Materials) for ventilation apparatus
- [ ] Update production log: 5× SimModule Single Pressure Sensor (MPXV7002GP) — produced 2026-01-21

### Data Collection (pending)
- [ ] Compression characterization -- infant manikins (DYMH-103 load cell)
- [ ] Ventilation characterization -- infant manikins (Bronkhorst EL-PRESS + SDP810)
- [ ] Unit-to-unit variation testing

### Analysis (pending)
- [ ] Reference model fitting (uncertainty envelope)
- [ ] Manikin comparison analysis
- [ ] Mechanical fidelity index calculation

### Writing (pending)
- [ ] Draft Section 1: Introduction
- [ ] Draft Section 2: Human Reference Model
- [ ] Draft Section 3: Uncertainty Envelope
- [ ] Draft Section 4: Characterization Protocol
- [ ] Draft Section 5: Results
- [ ] Draft Section 6: Fidelity Index
- [ ] Draft Section 7: Discussion
- [ ] Draft Section 8: Conclusion

### Oracles (pending)
- [x] Download MST author guidelines — **See `vv/oracles/MST_Author_Guidelines.md`**
- [ ] Find exemplar papers from MST special issues
- [ ] Document data availability requirements

---

## Delayed Decisions

### DR-001: Reference Model Scope (DECIDED — REVISED 2026-01-18)
**Decision:** Infant ventilation (primary) + Infant compression (primary)

**Rationale:**
- Only infant manikins available
- Test equipment suitable for infant manikins only
- Human reference exists for infant ventilation (Huang 2016, n=205)
- Animal surrogate reference for infant compression via:
  - **Route A:** Schmölzer piglet data (request existing force-displacement)
  - **Route B:** LUMC lamb measurements (perform ourselves)

**Piglet reference available:**
- Weight: 2.12 ± 0.17 kg (matches term infant)
- Age: 0-3 days, validated CPR model
- Force recorded in experiments → can extract stiffness

**Implications:**
- Ventilation: fidelity index against human reference (Huang 2016)
- Compression: fidelity index against animal surrogate reference
- DYMH-103 load cell (0-49 N) suitable for infant compression (14-30 N range)
- Bronkhorst EL-PRESS P-502C for airway pressure

See: `DR-001_reference_model_scope.md`

### DR-002: Manikin Selection (IN PROGRESS)
**Decision needed:** Which infant manikins to characterize?

**Status:** Sufficient manikins available (own inventory + WKZ access)

**Action:** Define test matrix - which models, how many units per model

### DR-004: Framework Terminology (DECISION NEEDED)
**Decision needed:** What to call the framework?

**Options:**
- **A:** Mechanical Fidelity Assessment
- **B:** Quantitative Fidelity Framework

**Context:** "Mechanical fidelity" is confusing—conflates with visual "high fidelity." Need terminology that emphasizes mechanical response vs appearance.

See: `working/DR-004_framework_terminology.md`

### DR-003: Lamb Reference Data (IN PROGRESS)
**Decision needed:** Can lamb chest compression data serve as reference for infant manikin validation?

**Potential source:** Arjen ten Pas (LUMC) - advisor, potential data provider

**If available, need:**
- Force-displacement measurements (stiffness k in N/mm)
- Hysteresis data (damping coefficient)
- Sample size (n) and weight range
- Publication/source for citation

**Hardware:** Transport dedicated CNC setup to LUMC via trailer. IMU (BHI360) as backup only.

**Impact:** Would enable fidelity index for compression (not just descriptive characterization)

---

## Collaborators

| Name | Affiliation | Role | Notes |
|---|---|---|---|
| Prof. dr. dr. Egon L. van den Broek | - | Promotor | |
| Dr. Jeroen Veen | - | Co-promotor | |
| Timo de Raad | WKZ, NRR, ERC | Co-author | Clinical/resuscitation expertise |
| Prof. dr. Arjen ten Pas | LUMC | Advisor | Potential lamb data provider (DR-003) |
| Jozua van Duuren | WKZ | Co-author/Advisor | Specialized nurse, involved in prior papers |

---

## Completed

### Session 2026-01-15 (Initial Setup)
- [x] Created `input_JV/` directory structure
- [x] Created `input_JV/vv/` V&V framework folders
- [x] Adapted `METHODOLOGY.md` from Proposition
- [x] Adapted `PAPER_VV_FRAMEWORK.md` from Proposition
- [x] Created `claim_registry.md` template with initial claims from outline
- [x] Created DR-000 (methodology adoption decision)
- [x] Created this backlog
- [x] Updated CLAUDE.md with new structure
- [x] Added AI-assisted review prompts adapted from TIM review guide:
  - `MST_Review_Prompt_Single_Stage.md` - comprehensive review
  - `MST_Review_Prompt_Stage1.md` - gate decision (proceed/reject)
  - `MST_Review_Prompt_Stage2.md` - detailed section-by-section review
  - `USAGE_GUIDE.md` - how to use the review prompts
- [x] Set up literature folder structure (`input_JV/literature/`)
- [x] Extracted human reference data from Proposition repo:
  - Adult compression: Lim 2024, Tomlinson 2007, Ruiz de Gauna 2023, Neurauter 2009
  - Infant ventilation: Huang 2016
  - Key quotes and evidence gaps identified
  - See `extracted_data_from_proposition.md`

---

## Notes

- Deadline: March 31, 2026
- Related paper: Proposition (perspective/conceptual framework)
- This paper: technical methodology + empirical data
- Key unique contribution: ventilation fidelity (less studied than compressions)

### Session 2026-01-15 (Literature V&V + Apparatus Planning)
- [x] Verified all verifiable P0 literature claims (C1-C5, V1-V2, I2-I3, D1-D2)
- [x] Identified Nysæther 2008 as primary source for human chest properties
- [x] Added Nysæther 2008 to paper_draft.md references
- [x] Contextualized Lim 2024 as manikin design (not human reference)
- [x] Created article summaries: Babic 2017, Nysæther 2008, Morin 2024
- [x] Updated claim registry to 48% coverage (10/21 verified)
- [x] Apparatus planning: load cell firmware needed, MPXV5010DP needed for ventilation
- Remaining P0 claims blocked by: M1-M2 (own work), RC1-RC2/RV1-RV3 (experiments)

### Session 2026-01-16 (Literature + Oracles)
- [x] Added new PDFs: Diedericks 2025, Reiss 2025, Ikeyama 2024, novel_cc_2025, survive_2024
- [x] Renamed PDFs to consistent format
- [x] Removed irrelevant jotten2008.pdf (telecommunications)
- [x] Strengthened V3 claim with Diedericks 2025 (FASEB review): "CCW ~3× CL term, ~5× preterm"
- [x] Created article summary: diedericks_2025_chest_wall_summary.md
- [x] Fetched MST author guidelines → `vv/oracles/MST_Author_Guidelines.md`
- [x] **Revised DR-001 scope:** infant ventilation (primary) + infant compression (secondary)
- [x] Updated claim registry with infant compression claims (RC1-RC3, C5, C7, D3, D4)
- [x] DYMH-103 load cell (0-49 N) confirmed suitable for infant compression (14-30 N)
- Next: DR-002 (manikin inventory), load cell integration, experimental protocol

### Session 2026-01-19 (Load Cell Integration)
- [x] **Load cell firmware completed and verified**
  - STM32F405 + HX711 (Sparkfun red) + DYMH-103 (0-5 kg)
  - Pin config: DAT→PB10, CLK→PB11, VDD+VCC→3.3V
  - Custom firmware: TARE, CAL (kg input), START/STOP streaming, READ, RAW, STATUS
  - Source: `software/loadcell/`
- [x] **HX711 wiring issue resolved**
  - Problem: VDD (3.3V) and VCC (5V) on different rails
  - Solution: Both VDD and VCC to 3.3V
- [x] **Calibration verified** (preliminary, with kitchen-weighed masses)

  | Gewicht | Verwacht | Gemeten | Fout |
  |---------|----------|---------|------|
  | 0 g | 0.00 N | 0.007 N | +0.007 N ✓ |
  | 301 g | 2.95 N | 3.081 N | +0.13 N |
  | 1.501 kg | 14.72 N | 14.691 N | -0.03 N ✓ |
  | 2.001 kg | 19.63 N | 19.628 N | -0.002 N ✓ |

  **Result:** Max error 0.13 N at low range, <0.035 N in working range (14-30 N). Within ±0.5 N spec.

- [x] **Calibration protocol created** — `software/loadcell/CALIBRATION.md`
- [x] **DR-005 created** — Acknowledgements registry
  - Herold Cremer (HAN): calibration weights, F1 class (kg range) available next week
  - Dr. Gertjan Lugthart (LUMC Pediatrics): facilitating collaboration
  - Arjan Bikkel, Peter Brouwer (Bronkhorst): pressure/flow sensor support
- [x] **3D printed calibration extension available** — `Calibration extension for Compression Actuator Load Cell.stl`

**Next steps:**
- Final calibration with Herold Cremer's F1 weights (volgende week)
- Begin manikin compression characterization

---

## Next Session Priorities

1. ~~**Load cell firmware integration**~~ — **DONE** ✓
2. **Final calibration with F1 weights** (Herold Cremer, HAN) — volgende week
3. **Inventory infant manikins** (DR-002)
4. **MPXV5010GP ×5 ordered** (2026-01-15) — pin-compatible replacement for MPXV5050
   - 0-10 kPa range, ±0.25 kPa accuracy
   - Backup / blocked airway detection
5. **Verify FLEXI-FLOW flow range setting** — currently 2 ln/min (TBC), may need 0.5 ln/min for infant volumes
6. **Bronkhorst: EL-PRESS (0-100 mbar) confirmed** (2026-01-16)
   - Bronkhorst will provide overpressure sensor
   - SI-traceable, factory calibrated
   - Primary sensor for Paw measurement + calibration reference

   **Order specification:**
   ```
   Model:    P-502C (EL-PRESS)
   Type:     Gauge (overpressure relative to atmosphere)
   Range:    0-100 mbar
   Use:      Airway pressure (Paw) measurement, infant ventilation
   Interface: RS232 or Modbus (compatible with existing MFM setup)
   ```

### Session 2026-01-21 (Literature & Gap Confirmation)
- [x] Inventorized O'Reilly 2024 — machine vs human CC in piglets; force profile > depth
- [x] Inventorized Thielen 2017 — human-like thorax design; classical manikins linear, humans nonlinear
- [x] Added claims I4 (force profile), I5 (linear vs nonlinear gap)
- [x] **Confirmed infant chest stiffness gap definitively:**
  - Kent 2010: "No experimental data exist" for pediatric F-D
  - Kent 2009: Youngest data ages 8-22yo (n=18)
  - Kent 2012: PMHS ages 6-7yo (youngest available)
  - Nysæther 2009: Expert consensus but N/mm unpublished
  - Kent 2010: Adult-to-pediatric scaling fails
- [x] Upgraded C5 to P0; added C6, C8
- [x] Claim registry: 13/21 verified (62%), 7/11 P0 (64%)
- [x] Validated DR-001 scope (ventilation fidelity index, compression descriptive only)
- [x] Decided NOT to attempt scaling — would undermine C8 claim

### Session 2026-01-30 (Model Variables)
- [x] **Defined model variables:**
  - Ventilation: Compliance (C) + Resistance (R) — standard respiratory mechanics
  - Compression: Stiffness (k) + Damping (d) — at standardized depth
- [x] **Age-dependent parameterization confirmed:**
  - Preterm: Ccw/CL ~5:1
  - Term (newborn): Ccw/CL ~3:1
  - Infant < 1 yr: Ccw/CL ~2.9:1
  - Child > 1 yr: Ccw/CL ~1.3:1
- [x] **Excluded dynamic softening** from infant model (adult phenomenon only)
- [x] Updated DR-001 with model variables and age categories
- [x] **Caught terminology confusion:** 15:2 is CPR compression:ventilation ratio (NRR protocol), NOT Ccw/CL ratio — added warning to DR-001
- [x] **Found Ccw/CL ratio by age:** Papastamelos 1995 (J Appl Physiol)
  - Preterm: ~5:1
  - Term: ~3:1
  - Infant < 1 yr: 2.86 ± 1.06
  - Child > 1 yr: 1.33 ± 0.36
  - Ratio **decreases** with age (chest wall stiffens via rib ossification)
- [x] **Verified Huang 2016 age basis:** Postnatal (not gestational) — term infants only (GA ≥37 wks)
- [x] **Found supporting sources:**
  - Stoecklin 2024: Preterm Crs/CL/Ccw at 36 wks PMA (no resistance data)
  - Diedericks 2025: Review with te Pas (LUMC) as co-author
- [x] **Created consolidated literature document:** `input_JV/literature/ventilation_reference_model_sources.md`
- [x] **Updated measurement tutorial with:**
  - Continuous flow method (Section 6.5) — recommended approach
  - Pneumatic supply chain: MS2-LFR → EL-PRESS → MFM → Manikin (Section 4.3)
  - Pressure range analysis: 10-50 mbar typical, max ~100 mbar
  - Updated quick reference card

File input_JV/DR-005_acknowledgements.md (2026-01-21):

# DR-005: Acknowledgements

**Status:** OPEN (add as contributions occur)

**Date:** 2026-01-19

---

## Decision

Maintain a registry of individuals to acknowledge in the MST paper for their contributions to the research.

---

## Acknowledgements Registry

| Name | Affiliation | Contribution |
|---|---|---|
| Herold Cremer | HAN | Calibration weights and measurement discussion |
| Gertjan Lugthart | LUMC (Pediatrics) | Facilitating collaboration with Arjen ten Pas |
| Arjan Bikkel | Bronkhorst | Pressure/flow sensor support |
| Peter Brouwer | Bronkhorst | Pressure/flow sensor support |

---

## Draft Acknowledgement Text

> We thank Herold Cremer (HAN University of Applied Sciences) for support with calibration equipment, Dr. Gertjan Lugthart (LUMC, Department of Pediatrics) for facilitating collaboration, and Arjan Bikkel and Peter Brouwer (Bronkhorst High-Tech B.V.) for technical support with pressure and flow instrumentation.

---

## Notes

- Add others as project progresses
- Check preferred name/title format before submission
- Bronkhorst may want company acknowledgement format verified

---

*Last updated: 2026-01-19*

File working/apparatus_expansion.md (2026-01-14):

# Apparatus Expansion: TIM → Engineering Fidelity

**Goal:** Expand current IEEE TIM sensor validation apparatus to enable manikin mechanical characterization for the Engineering Fidelity paper.

---

## 1. Current Capabilities vs. Requirements

### Compression Apparatus

| Capability | TIM Paper | Engineering Fidelity | Gap |
|---|---|---|-----|
| Displacement measurement | ✅ ToF sensor (±2mm) | ✅ Required | None |
| Automated actuation | ✅ CNC (±0.01mm) | ✅ Required | None |
| **Force measurement** | ❌ Not present | ✅ Required | **LOAD CELL NEEDED** |
| Thermal monitoring | ✅ SHT45 | ✅ Required | None |
| Data acquisition | ✅ STM32F405 | ✅ Required | None |

**Critical gap:** No load cell for force measurement. Without force, cannot calculate stiffness (k = F/x) or damping.

### Ventilation Apparatus

| Capability | TIM Paper | Engineering Fidelity | Gap |
|---|---|---|-----|
| Volume delivery | ✅ Syringe actuator | ✅ Required | None |
| Pressure measurement | ✅ DPS (±0.75%) | ✅ Required | None |
| Flow reference | ✅ MFM (±0.8%) | ✅ Required | None |
| **Compliance derivation** | ❌ Not calculated | ✅ Required | **SOFTWARE** |
| **Resistance derivation** | ❌ Not calculated | ✅ Required | **SOFTWARE** |

**Gap:** Software extension needed to calculate C and R from existing P/V data.

---

## 2. Compression Apparatus Expansion

### 2.1 Load Cell Integration

**Requirements:**
- Force range: 0–500 N (based on Tomlinson 2007: mean ~300 N, max ~500 N)
- Resolution: ≤1 N (for stiffness calculation at ~10 N/mm)
- Sampling rate: ≥50 Hz (synchronized with ToF)
- Interface: Compatible with STM32F405 (analog or I2C/SPI)

**Recommended Options:**

| Option | Model | Range | Resolution | Interface | Est. Cost |
|---|---|---|---|---|---|
| A | SparkFun HX711 + TAL220 | 0–50 kg (~500 N) | ~0.05 N | HX711 ADC | €20–30 |
| B | Futek LSB200 | 0–500 N | 0.1 N | Analog | €200–400 |
| C | TE FC22 | 0–445 N | 0.5 N | Analog | €50–100 |

**Recommendation:** Start with **Option A** (HX711 + TAL220 load cell) for rapid prototyping. Low cost, well-documented, Arduino-compatible. Upgrade to Option B/C if precision issues arise.

### 2.2 Mechanical Integration

**Mounting approach:**
```
                    CNC Actuator
                         │
                    ┌────┴────┐
                    │ Load    │  ← Force measurement
                    │ Cell    │
                    └────┬────┘
                         │
                    ┌────┴────┐
                    │ Piston  │  ← Compression surface
                    │ Plate   │
                    └─────────┘
                         │
                    ┌────┴────┐
                    │ Manikin │  ← ToF sensor inside
                    │ Chest   │     measures displacement
                    └─────────┘
```

**Key considerations:**
- Load cell in series between actuator and compression plate
- Rigid mounting to avoid compliance artifacts
- Calibrate with known weights before manikin testing

### 2.3 Software Updates

**New data fields (extend existing JSON structure):**
```json
{
  "timestamp": 0.025,
  "cnc_z_pos": -20.0,
  "distance_mm": 20.1,
  "force_N": 210.5,      // NEW
  "range_status": 0,
  "signal_strength": 5032
}
```

**New analysis functions:**
```python
def calculate_stiffness(force, displacement):
    """Linear regression: k = dF/dx [N/mm]"""
    return np.polyfit(displacement, force, 1)[0]

def calculate_damping(force, displacement, velocity, frequency):
    """Hysteresis loop analysis: d = W_loop / (2π f A²)"""
    loop_area = np.trapz(force, displacement)  # Signed area
    amplitude = np.max(displacement) - np.min(displacement)
    return loop_area / (2 * np.pi * frequency * amplitude**2)

def fit_gruben_model(force, displacement, velocity):
    """Fit F = k1*z + k2*z² + k3*z³ + k4*z⁴ + d0*ż + d1*z*ż"""
    # Construct feature matrix
    # Return coefficients [k1, k2, k3, k4, d0, d1]
    pass
```

### 2.4 Calibration Protocol

**Load cell calibration:**
1. Zero with no load
2. Apply known weights: 0, 100, 200, 300, 400, 500 N
3. Record raw ADC values
4. Fit linear calibration: F = a × ADC + b
5. Verify with intermediate weights
6. Document calibration coefficients and uncertainty

**Cross-validation:**
- Compare actuator force (from load cell) with expected force from manikin datasheet
- Verify stiffness calculation with known spring (if available)

---

## 3. Ventilation Apparatus Expansion

### 3.1 Sensor Requirements Analysis

**Calculating respiratory compliance and resistance requires:**
1. **Pressure (P)** — airway pressure during ventilation cycle
2. **Flow (V̇)** — volumetric flow rate
3. **Volume (V)** — derived by integrating flow, or from direct measurement

**Formulas:**
- Compliance: C_rs = ΔV / ΔP [mL/cmH₂O]
- Resistance: R_rs = ΔP / V̇ [cmH₂O·s/L]

### 3.2 Available Sensors

| Sensor | Parameter | Range | Accuracy | Suitability |
|---|---|---|---|---|
| **Bronkhorst MFM FF-M11** | Flow | 4–2000 mln/min | ±0.8% Rd + ±0.2% FS | ✅ Excellent |
| **Bronkhorst MFM FF-M11** | Pressure | 0–17 bar(a) max | ±0.5% FS | ⚠️ Verify range setting |
| **Sensirion SDP810-500Pa** | Pressure | ±500 Pa | ±0.75% Rd | ✅ Appropriate |

**Analysis:**

The MFM has integrated pressure sensors (upstream P1 and downstream P2) with maximum range 0–17 bar(a). At full scale:
- ±0.5% FS would give ±0.085 bar = ±85 mbar ≈ ±85 cmH₂O resolution
- Ventilation pressures are typically 0–50 cmH₂O
- **At full 17 bar range, the MFM pressure sensors may be too coarse for ventilation mechanics**

However, the pressure range may be configurable to a narrower span more suitable for low-pressure applications. Verify in FlowSuite or instrument settings whether a lower pressure range can be selected, which would improve resolution proportionally.

The DPS (SDP810-500Pa) is designed for low differential pressures:
- Range: ±500 Pa ≈ ±5 cmH₂O
- Resolution: suitable for ventilation measurements

**⚠️ Range verification needed:** Typical infant PIP is 15–25 cmH₂O (~1500–2500 Pa). If using SDP810-500Pa (±500 Pa), verify this is sufficient or consider SDP800-series with higher range (e.g., SDP816 with 500–1000 Pa full scale, or external amplification).

### 3.3 Recommended Configuration

```
                    Ventilation Circuit
                          │
        ┌─────────────────┼─────────────────┐
        │                 │                 │
   ┌────┴────┐      ┌─────┴─────┐     ┌─────┴─────┐
   │ Syringe │      │    MFM    │     │   DPS     │
   │ Actuator│      │  FF-M11   │     │ SDP810    │
   └────┬────┘      └─────┬─────┘     └─────┬─────┘
        │                 │                 │
        │            FLOW ✅          PRESSURE ✅
        │          (4–2000 mln/min)    (±500 Pa)
        │          ±0.8% Rd + 0.2% FS  ±0.75% Rd
        │                 │                 │
        └─────────────────┴─────────────────┘
                          │
                    ┌─────┴─────┐
                    │  Manikin  │
                    │  Airway   │
                    └───────────┘
```

**Sensor roles:**
| Measurement | Sensor | Why |
|---|---|-----|
| Flow | MFM | High accuracy, SI-traceable, real-time |
| Pressure | DPS | Appropriate range for airway pressures |
| Volume | Derived | Integrate flow or use syringe position |

### 3.4 Data Requirements for Mechanics Calculation

**Minimum data logged per cycle:**
- Timestamp (ms resolution)
- Pressure from DPS (Pa or cmH₂O)
- Flow from MFM (mln/min → L/s)
- Syringe position (optional backup for volume)

**Derived parameters:**
- Volume: V(t) = ∫ V̇(t) dt
- Compliance: C = ΔV / ΔP
- Resistance: R = ΔP / V̇_peak

### 3.5 Compliance Calculation Method

**Static compliance (quasi-static conditions):**
- Measure plateau pressure after inspiratory hold
- C_rs = V_T / (P_plat - PEEP)

**Dynamic compliance (during breathing):**
- Use pressure and volume at end-inspiration
- C_dyn = V_T / (PIP - PEEP)

**Our approach:** Since the syringe actuator provides controlled volume delivery, we can use dynamic compliance during the ventilation cycle. The MFM provides high-accuracy volume reference.

### 3.6 Resistance Calculation Method

**Peak flow method:**
- R_rs = (PIP - P_plat) / V̇_peak

**Mean flow method:**
- R_rs = mean pressure / mean flow during inspiration

**Our approach:** Use instantaneous pressure at peak flow, since we log synchronized P and V̇ data.

### 3.7 Unit Conversions

**Reference data (Huang 2016) uses SI units:**

| Parameter | Huang 2016 | Our measurement | Conversion |
|---|---|---|---|
| Compliance | mL/kPa | mL/cmH₂O | C[mL/kPa] = C[mL/cmH₂O] × 10.197 |
| Resistance | kPa/L/s | cmH₂O/L/s | R[kPa/L/s] = R[cmH₂O/L/s] / 10.197 |

**Conversion factor:** 1 kPa = 10.197 cmH₂O

### 3.8 Hardware Requirements Summary

**No additional hardware needed** — existing sensors are sufficient:

| Component | Status | Notes |
|---|---|---|
| Flow sensor | ✅ MFM available | SI-traceable, real-time logging |
| Pressure sensor | ✅ DPS available | Appropriate range for ventilation |
| Volume actuator | ✅ Syringe available | Calibrated with 100 mL syringe |
| Data acquisition | ✅ STM32F405 | Synchronized logging |

**Software required:**
- Extend data logging to include both MFM (flow) and DPS (pressure)
- Implement compliance/resistance calculation
- Unit conversion functions
- Visualization (P-V loops, flow-volume curves)

---

## 4. Implementation Plan

### Phase 1: Load Cell Integration (Week 1)

| Day | Task |
|-----|---|
| 1 | Order HX711 + TAL220 load cell kit |
| 2–3 | Design mounting bracket (3D print or machine) |
| 4 | Wire load cell to STM32F405 |
| 5 | Write HX711 driver code |
| 6 | Calibrate with known weights |
| 7 | Verify against reference (bathroom scale as sanity check) |

**Deliverable:** Force measurement integrated into compression apparatus

### Phase 2: Software Updates (Week 1–2)

| Task | Priority |
|---|---|
| Add force field to data acquisition | HIGH |
| Implement stiffness calculation | HIGH |
| Implement damping calculation | HIGH |
| Implement Gruben polynomial fitting | MEDIUM |
| Add C/R calculation to ventilation analysis | HIGH |
| Unit conversion functions | HIGH |
| Updated visualization (F-D curves, P-V loops) | MEDIUM |

**Deliverable:** Analysis scripts ready for mechanical characterization

### Phase 3: Validation (Week 2)

| Test | Success Criteria |
|---|---|
| Load cell linearity | R² > 0.999 |
| Load cell repeatability | CV < 1% |
| Force-displacement on test spring | Stiffness within 5% of known value |
| Ventilation C/R on test lung | Values within expected range |

**Deliverable:** Validated apparatus ready for manikin testing

---

## 5. Bill of Materials

### New Components Required

| Item | Quantity | Est. Cost | Source |
|---|---|---|---|
| TAL220 load cell (50 kg) | 1 | €10 | SparkFun/AliExpress |
| HX711 ADC module | 1 | €5 | SparkFun/AliExpress |
| Mounting hardware | 1 set | €20 | Local hardware store |
| Calibration weights (if needed) | 1 set | €30 | Amazon |
| **Total** | | **~€65** | |

### Optional Upgrades

| Item | Purpose | Est. Cost |
|---|---|---|
| Futek LSB200 load cell | Higher precision | €300 |
| Calibrated test spring | Stiffness validation | €50 |
| Test lung (calibrated) | Ventilation validation | €100 |

---

## 6. Risk Assessment

| Risk | Likelihood | Impact | Mitigation |
|---|---|---|---|
| Load cell noise | Medium | Medium | Averaging, filtering, shielding |
| Mechanical compliance in mounting | Medium | High | Rigid design, calibrate in-situ |
| HX711 sample rate too slow | Low | Medium | Can achieve 80 Hz; sufficient |
| Ventilation C/R calculation invalid | Low | High | Validate against test lung |

---

## 7. Quick Start Checklist

**Before ordering:**
- [ ] Confirm CNC actuator can accommodate load cell in series
- [ ] Measure available space for load cell mounting
- [ ] Verify STM32F405 has available GPIO/ADC pins

**After receiving components:**
- [ ] Assemble and calibrate load cell
- [ ] Update firmware for force data acquisition
- [ ] Update Python scripts for force analysis
- [ ] Validate on known reference (spring or weights)
- [ ] Test on one manikin before full data collection

---

## 8. Summary

**Hardware changes required:**
- Add load cell (HX711 + TAL220) to compression apparatus — ~€65, ~1 week

**Software changes required:**
- Force data acquisition and logging
- Stiffness, damping, Gruben fitting functions
- Compliance/resistance calculation for ventilation
- Unit conversions and updated visualizations

**No changes needed:**
- Ventilation hardware (DPS, MFM already sufficient)
- Displacement measurement (ToF already validated)
- Environmental monitoring (SHT45 already integrated)

**Estimated timeline:** 2 weeks from component arrival to validated apparatus

---

*Document created: January 2026*

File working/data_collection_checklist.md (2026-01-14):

# Data Collection Checklist

**Paper:** Engineering Fidelity of CPR Training Manikins
**Deadline:** March 31, 2026
**Target:** Complete data collection by mid-February 2026

---

## 1. Pre-Collection Setup

### 1.1 Equipment Verification
- [ ] CNC actuator (BlackBox X32) operational and calibrated
- [ ] VL53L4CD ToF sensor firmware updated (62.9mm offset correction)
- [ ] Load cell calibrated against reference weights
- [ ] Sensirion SDP810-500Pa DPS functional
- [ ] Bronkhorst MFM SI-traceable certificate current
- [ ] Mitutoyo caliper calibration verified
- [ ] SHT45 environmental sensor functional
- [ ] STM32F405 data acquisition tested
- [ ] 100 mL calibration syringe available

### 1.2 Software Verification
- [ ] `cpr_multi_cycle_tester.py` tested
- [ ] `cpr_compression_validator.py` tested
- [ ] Ventilation controller firmware uploaded
- [ ] Data logging scripts verified (JSON/CSV output)
- [ ] Analysis scripts prepared

### 1.3 Manikins Secured
| Manikin | Manufacturer | Available | Serial # |
|---|---|---|---|
| [ ] Resusci Baby QCPR | Laerdal | | |
| [ ] Little Junior QCPR | Laerdal | | |
| [ ] Resusci Anne QCPR | Laerdal | | |
| [ ] Ambu Baby | Ambu | | |
| [ ] [Additional infant] | | | |
| [ ] [Additional adult] | | | |

**Goal:** Minimum 3 infant + 2 adult manikins; ideally 2 units of same model for unit-to-unit variation

---

## 2. Compression Characterization

### 2.1 Per-Manikin Protocol

**Pre-test:**
- [ ] Record manikin ID, serial number, manufacture date (if available)
- [ ] Photograph manikin chest area
- [ ] Position manikin on rigid surface
- [ ] Mount actuator assembly
- [ ] 30-minute thermal stabilization
- [ ] Record ambient T (target: 22±2°C) and RH (target: 45±5%)
- [ ] Zero calibration against Mitutoyo caliper

**Test Sequence:**

| Test | Description | Cycles | Est. Time |
|---|---|---|---|
| [ ] Depth sweep | 10, 20, 30, 40, 50 mm | 5 × 20 = 100 | 15 min |
| [ ] Rate variation | 100, 110, 120 CPM @ 40mm | 3 × 20 = 60 | 10 min |
| [ ] Extended cycling | 150 cycles @ 40mm | 150 | 15 min |
| **Total** | | **310 cycles** | **~40 min** |

**Post-test:**
- [ ] Verify no manikin damage
- [ ] Export data (JSON + CSV)
- [ ] Quick visual inspection of force-displacement curves
- [ ] Note any anomalies

### 2.2 Data Files Required

Per manikin:
```
/data/compressions/{manikin_id}/
├── metadata.json          # Manikin info, environmental conditions
├── depth_sweep.csv        # Force, displacement, time
├── rate_variation.csv
├── extended_cycling.csv
└── plots/
    ├── force_displacement.png
    └── hysteresis_loops.png
```

### 2.3 Derived Parameters to Extract

| Parameter | Symbol | Unit | Method |
|---|---|---|---|
| Stiffness | k | N/mm | Linear regression slope |
| Compression damping | d_c | N·s/mm | Hysteresis analysis |
| Recoil damping | d_r | N·s/mm | Hysteresis analysis |
| Nonlinearity coefficients | k₁–k₄ | — | Gruben polynomial fit |
| Fatigue drift | Δk | % | Extended cycling trend |

---

## 3. Ventilation Characterization

### 3.1 Per-Manikin Protocol

**Pre-test:**
- [ ] Record manikin ID
- [ ] Inspect airway patency
- [ ] Connect ventilation apparatus
- [ ] Leak test (seal mask/tube connection)
- [ ] Configuration-specific K calibration (grid search)
- [ ] Record ambient T and RH

**Test Sequence:**

| Test | Description | Cycles | Est. Time |
|---|---|---|---|
| [ ] Volume sweep | 12.25, 24.5, 36.75, 49.0, 61.25, 73.5 mL | 6 × 100 = 600 | 45 min |
| [ ] Clinical target | 24.5 mL (infant) | 200 | 15 min |
| **Total** | | **800 cycles** | **~60 min** |

**Post-test:**
- [ ] Export data
- [ ] Verify calibration coefficient stability
- [ ] Note any leaks or anomalies

### 3.2 Data Files Required

Per manikin:
```
/data/ventilations/{manikin_id}/
├── metadata.json          # Manikin info, K coefficient, conditions
├── volume_sweep.csv       # Pressure, flow, volume, time
├── clinical_target.csv
└── plots/
    ├── volume_accuracy.png
    └── pressure_volume_loops.png
```

### 3.3 Derived Parameters to Extract

| Parameter | Symbol | Unit | Method |
|---|---|---|---|
| Compliance | C_rs | mL/cmH₂O | V / ΔP |
| Resistance | R_rs | cmH₂O/L/s | ΔP / flow |
| Calibration coefficient | K | Pa⁻¹/²·mL·s⁻¹ | Grid search |
| Volume accuracy | RMSE | % | vs. MFM reference |

---

## 4. Reference Envelope Comparison

### 4.1 Compression (Adults)

| Parameter | Human Reference | Unit | Source |
|---|---|---|---|
| Stiffness | 92–113 | N/cm | Ruiz de Gauna 2023 |
| Compression damping | 2.4–3.3 | N·s/cm | Ruiz de Gauna 2023 |
| Recoil damping | 4.0–5.8 | N·s/cm | Ruiz de Gauna 2023 |
| Nonlinearity | Required | — | Multiple |

### 4.2 Ventilation (Infants)

| Parameter | Human Reference | Unit | Source |
|---|---|---|---|
| Compliance | 78–171 | mL/kPa | Huang 2016 |
| Resistance | 3.74–6.39 | kPa/L/s | Huang 2016 |

---

## 5. Analysis Checklist

### 5.1 Per-Manikin Analysis
- [ ] Calculate stiffness (k) ± uncertainty
- [ ] Calculate damping (d_c, d_r) ± uncertainty
- [ ] Fit Gruben polynomial, extract coefficients
- [ ] Calculate compliance (C_rs) ± uncertainty
- [ ] Calculate resistance (R_rs) ± uncertainty
- [ ] Compare to reference envelope (within/outside)

### 5.2 Cross-Manikin Analysis
- [ ] Generate comparison table (all manikins vs. reference)
- [ ] Plot force-displacement overlays
- [ ] Calculate Engineering Fidelity Index (EFI) for each
- [ ] Rank manikins by EFI
- [ ] Assess unit-to-unit variation (same model)

### 5.3 Figures for Paper

| Figure | Description | Status |
|---|---|---|
| Fig. 1 | Compression apparatus schematic | [ ] |
| Fig. 2 | Ventilation apparatus schematic | [ ] |
| Fig. 3 | Force-displacement curves (all manikins vs. human) | [ ] |
| Fig. 4 | Hysteresis loop comparison | [ ] |
| Fig. 5 | Ventilation compliance/resistance vs. reference | [ ] |
| Fig. 6 | EFI ranking bar chart | [ ] |

### 5.4 Tables for Paper

| Table | Description | Status |
|---|---|---|
| Table 1 | Human reference values (compression) | [x] In draft |
| Table 2 | Human reference values (ventilation) | [x] In draft |
| Table 3 | Manikin compression parameters | [ ] |
| Table 4 | Manikin ventilation parameters | [ ] |
| Table 5 | EFI scores and ranking | [ ] |
| Table 6 | Unit-to-unit variation | [ ] |

---

## 6. Timeline

| Week | Dates | Activity |
|---|---|---|
| 1 | Jan 13–19 | Equipment setup, software verification |
| 2 | Jan 20–26 | Compression testing (3–4 manikins) |
| 3 | Jan 27–Feb 2 | Compression testing (remaining) + analysis |
| 4 | Feb 3–9 | Ventilation testing (all manikins) |
| 5 | Feb 10–16 | Analysis, EFI calculation, figures |
| 6 | Feb 17–23 | Write Section 5, revise draft |
| 7 | Feb 24–Mar 2 | Co-author review |
| 8 | Mar 3–9 | Revisions |
| 9 | Mar 10–16 | Final polish |
| 10 | Mar 17–23 | Buffer |
| 11 | Mar 24–31 | **Submit by March 31** |

---

## 7. Risk Mitigation

| Risk | Mitigation |
|---|---|
| Equipment failure | Test all equipment in Week 1; have backup sensors |
| Manikin unavailability | Confirm access NOW; identify alternatives |
| Time overrun | Prioritize infant manikins (novel contribution) |
| Unexpected results | Document everything; results are results |
| Load cell issues | Can still characterize displacement/stiffness from depth data |

---

## 8. Quick Reference: Key Numbers

**Compression targets:**
- Adult: 50 mm depth, 100–120 CPM
- Infant: 40 mm depth (~1/3 thorax)

**Ventilation targets (3.5 kg infant):**
- Volume: 21–28 mL (ERC 2025)
- Test range: 12.25–73.5 mL

**Human reference (adult compression):**
- Stiffness: 104.9 N/cm (95% CI: 102–108)
- Recoil damping 1.7× compression damping

**Human reference (infant ventilation):**
- Compliance: 78–171 mL/kPa (age-dependent)
- Resistance: 3.74–6.39 kPa/L/s (age-dependent)

---

*Checklist created: January 2026*
*Last updated: [date]*

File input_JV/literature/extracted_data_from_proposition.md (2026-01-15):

# Extracted Data from Proposition Repository

**Source:** `C:\local_dev\Proposition\`
**Extracted:** 2026-01-15
**Purpose:** Reuse verified literature data for MST paper human reference model

---

## Human Chest Mechanics - Adults (Compressions)

### Stiffness Data

| Property | Value | Source | Clinical Context | Claim |
|---|---|---|---|---|
| **Stiffness at 50mm** | 4–10 N/mm | Lim et al. 2024 | Wide variation between patients | C1 |
| **Stiffness at 50mm** | 7.7–8.1 N/mm | Neurauter et al. 2009 | 90 cardiac arrest patients | - |
| **Stiffness (initial)** | 10.5 N/mm | Ruiz de Gauna et al. 2023 | 615 OHCA patients, 1.1M compressions | - |
| **Damping at 30mm** | 0.08–0.38 N·s/mm | Lim et al. 2024 | Viscoelastic response | C2 |
| **Force for 38mm depth** | 27.5 ± 13.6 kg | Tomlinson et al. 2007 | 91 OHCA patients | - |
| **Force-depth curve** | Non-linear | Tomlinson et al. 2007 | Stiffness increases with depth | C3 |

### Dynamic Stiffness Changes (Ruiz de Gauna et al., 2023)

**Dataset:** 1,156,608 chest compressions from 615 OHCA patients

| Property | At CPR Start | After 3000 Compressions | Change |
|---|---|---|---|
| Stiffness (k) | 10.5 N/mm | ~6.9 N/mm | **-34.6%** |
| Compression damping | 2.87 N·s/cm | ~1.5 N·s/cm | **-48.8%** |
| Recoil damping | 4.89 N·s/cm | ~3.1 N·s/cm | **-37.2%** |

**Key Finding:** Human chests soften ~35% during prolonged CPR. Manikins don't simulate this.

---

## Human Ventilation Mechanics - Infants

| Property | Value | Source | Age Range | Claim |
|---|---|---|---|---|
| **Compliance** | ~80 mL/kPa | Huang et al. 2016 | 1-24 weeks | V1 |
| **Compliance** | ~170 mL/kPa | Huang et al. 2016 | 73-96 weeks | V1 |
| **Resistance** | ~6 kPa/L/s | Huang et al. 2016 | 1-24 weeks | V2 |
| **Resistance** | ~4 kPa/L/s | Huang et al. 2016 | 73-96 weeks | V2 |

---

## Key Quotes (Verified)

### Tomlinson et al. 2007 - Manikin Problem

> "Commonly used CPR training manikins...usually have spring loaded chests with a **linear relationship between force and depth**."

> "The elastic force in manikins is **higher than in humans at the onset of compression and lower at higher depths** of compression."

### Lim et al. 2024 - Manufacturer Gap

> "Mechanical properties of commercially available CPR training manikins remain constant and **no information on these properties is provided by the manufacturers**."

---

## Evidence Gaps Confirmed

### Well-Characterized (Strong Evidence)
- [x] Adult chest stiffness (Tomlinson, Neurauter, Lim, Ruiz de Gauna)
- [x] Adult chest damping (Lim 2024)
- [x] Adult dynamic stiffness changes (Ruiz de Gauna 2023)
- [x] Infant respiratory compliance (Huang 2016)

### Poorly Characterized (Weak Evidence)
- [ ] Infant chest compression mechanics
- [ ] Adult ventilation mechanics
- [ ] Manikin vs human systematic comparison
- [ ] Unit-to-unit manikin variation

### Evidence Landscape Summary (from Proposition Chapter 8.5)

| Dimension | Adult Compressions | Infant Compressions | Adult Ventilations | Infant Ventilations |
|---|---|---|---|---|
| Human clinical data | **Strong** | **Weak** | **Weak** | **Very weak** |
| Manikin vs human comparison | Partial (Lim 2024) | **None** | **None** | **None** |

**MST Paper Contribution:** Systematic manikin characterization to fill "Manikin vs human comparison" gaps.

---

## Training-Performance Gap Evidence

### Lund-Kordahl et al. 2019

| Metric | Basic Training | Advanced Training | Gap |
|---|---|---|-----|
| Effective ventilations | 16.4% | 85.7% | **5× difference** |
| Correct compression depth | 40.6% | 82.1% | 2× difference |

**Key Finding:** Ventilations show the largest training-performance gap.

---

## BibTeX Keys (from Proposition references.bib)

```bibtex
@article{lim2024variable,
  title={Variable Stiffness and Damping Mechanism for CPR Manikin...},
  author={Lim, Hyunwoo and Shin, Dong-Ah and Sim, Jaesoon and others},
  journal={IEEE J Transl Eng Health Med},
  year={2024}
}

@article{tomlinson2007force,
  title={Compression force-depth relationship during out-of-hospital CPR},
  author={Tomlinson, AE and Nysaether, J and Kramer-Johansen, J and others},
  journal={Resuscitation},
  volume={72},
  pages={364--370},
  year={2007}
}

@article{ruizdegauna2023characterization,
  title={Characterization of mechanical properties of adult chests...},
  author={Ruiz de Gauna, Sofía and Gutiérrez, JJ and Sandoval, CL and others},
  journal={Comput Methods Programs Biomed},
  volume={242},
  pages={107847},
  year={2023}
}

@article{neurauter2009comparison,
  title={Comparison of mechanical characteristics of the human and porcine chest...},
  author={Neurauter, A and Nysaether, J and Kramer-Johansen, J and others},
  journal={Resuscitation},
  year={2009}
}

@article{huang2016reference,
  title={Reference values for resistance and compliance in healthy infants},
  author={Huang, J and others},
  journal={J Thorac Dis},
  volume={8},
  number={3},
  pages={513--519},
  year={2016}
}

@article{lundkordahl2019training,
  title={Relationship between level of CPR training, self-reported skills...},
  author={Lund-Kordahl, I and Mathiassen, M and Melau, J and others},
  journal={BMC Emerg Med},
  year={2019}
}
```

---

## Files to Obtain for Verification

### Priority 1 - Core Reference Data
- [ ] Lim et al. 2024 (IEEE JTEHM) - stiffness/damping values
- [ ] Tomlinson et al. 2007 (Resuscitation) - force-depth curves
- [ ] Ruiz de Gauna et al. 2023 (Comput Methods Programs Biomed) - dynamic changes
- [ ] Huang et al. 2016 (J Thorac Dis) - infant ventilation reference

### Priority 2 - Supporting
- [ ] Neurauter et al. 2009 - cross-species comparison
- [ ] Papastamelos et al. 1995 - developmental changes

---

*Data extracted from Proposition repository chapter_engineering_fidelity.md, records_jk/literature_search_mechanical_fidelity.md, and records_jk/key_quotes.md*

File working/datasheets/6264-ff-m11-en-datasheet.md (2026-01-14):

# 6264-ff-m11-en-datasheet

## Page 1

Technical specifications
Measurement & control
Type of media
Gases
Flow range
0.5 / 2 / 5 / 20 ln/min
Accuracy
up to ±0.5% Rd plus ±0.1% FS
Repeatability
< ±0.2% Rd
Turndown ratio
up to 1:1000
Multi fluid capability
embedded gas data for 22 unique gases plus any
mixture of these gases
Pre-installed gases
C2H2 Air C3H4 #1 Ar CO2 CO C3H6 #1 D2 #1
C2H6 C2H4 He H2 Kr CH4 Ne N2 N2O O2 C3F8
C3H6 #2 C3H8 C3H4 #2
Response time (sensor)
< 30 ms (T63)
Operating temperature
0…+50 °C (32°F - 122°F)
Temperature sensitivity
Flow sensor: zero 0.015% FS/ºC; span 0.05%
Rd/ºC; Pressure sensors: zero 0.16 mbar/ºC;
span 0.05% Rd/ºC
Leak integrity, outboard
tested < 2 x 10-9 mbar l/s He
Long term stability
<0.5% FS over period of 3 years, then <0.2% FS
per year
Pressure sensitivity
standard: < 0.15% Rd/bar typical N2; with
pressure correction: typical factor 5 improved
Pressure range sensor
0...17 bar(a)
Mounting
any position, attitude sensitivity negligible
Warm-up time
30 minutes
Storage/transport conditions
0...+50°C, max. 95% RH (non-condensing)
Approvals
Marking
CE
Mechanical specs
Pressure rating (PN)
16
Ingress protection
IP40
Surface roughness wetted parts
<1.6 μm Ra (<0.8 μm Ra for stainless steel
body)
Material wetted parts
aluminium, stainless steel, silicon nitride,
epoxy, aluminiumoxide, glas, FKM
Sealing material
FKM 51415; for other materials contact factory
Process connections
1/8" BSPP female thread (ISO1179-1);
compression type, push-in or face seal
(VCR/VCO) couplings
Weight
225 g with Aluminium body, 325 g with SS 316
body; add 50 g for Ethernet interface
Electrical properties
Power supply
+24 Vdc ± 10%
Power consumption
0.5 Watt typical, add 0.9 Watt for EtherNet
communication
Digital communication
Modbus-RTU, Modbus-ASCII, FLOW-BUS,
EtherCAT®, EtherNet/IP, Modbus-TCP,
POWERLINK, PROFINET
Electrical interfaces
Service interface
USB-C, Bluetooth
Power (main connector)
9-pin D-sub (male)
Function (main connector)
RS485
Modbus RTU/ASCII/FLOW-BUS
9-pin D-sub (male, main connection)
Modbus TCP / EtherNet/IP / EtherCAT®/
PROFINET / POWERLINK
2x RJ45
Last modified 05-05-2025.
© Bronkhorst High-Tech B.V. All rights reserved.
The specifications are subject to change without notice. The products described herein and this document are subject to specific legal disclaimers as
set forth on www.bronkhorst.com/disclaimer. For more information and detailed advice, please contact the local Bronkhorst sales partner. Contact
details can be found at www.bronkhorst.com/contact.
EN
FLEXI-FLOW Compact
FF-M11
Built-to-order mass flow and pressure meter

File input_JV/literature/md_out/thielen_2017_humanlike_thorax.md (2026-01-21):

# Thielen et al. 2017 - Human-Like Thorax CPR Manikin

**Full Citation:** Thielen M, Joshi R, Delbressine F, Bambang Oetomo S, Feijs L. An innovative design for cardiopulmonary resuscitation manikins based on a human-like thorax and embedded flow sensors. *Proc IMechE Part H: J Engineering in Medicine*. 2017;1-7. doi:10.1177/0954411917691555

**PDF:** `input_JV/literature/pdfs/thielen_2017_humanlike_thorax.pdf`

**Extracted:** 2026-01-21

---

## Summary

Design paper from TU Eindhoven presenting a novel CPR manikin with anatomically realistic thorax, embedded cardiovascular/respiratory systems, and flow sensors. Key contribution: demonstrates that classical manikins have linear force-displacement while humans (and their design) show nonlinear behavior.

**Core argument:** Improving physical/anatomical fidelity → increases functional/physiological fidelity.

---

## The Problem with Classical Manikins

### Single Spring-Damper Configuration (Figure 1)

Classical manikins use a single spring-damper system where:
- Displacement is **independent of compression location** (unrealistic)
- Sternum is stiff and does not tilt
- Force-displacement is essentially **linear**

> "like other classical designs, these manikins consist of a single spring–damper configuration... This displacement is independent of the axial location of the applied force since the manikin sternum is stiff and does not tilt, a behaviour unrealistic when compared to the human body."

### Even Advanced Manikins Fail

> "Despite the aforementioned recommendations and a clinical desire for physiologically and anatomically high-fidelity manikin designs, even the technologically most advanced manikins such as the **SimMan 3G** (Laerdal) and **Apollo** (CAE healthcare) **do not fulfil all these requirements**."

---

## Force-Displacement Model

### Gruben et al. Polynomial Model (Refs 7-9)

The compression force F consists of elastic (Fe) and damping (Fd) components:

```
F = Fe + Fd

Fe = k(z) · z
k(z) = k₁ + k₂·z + k₃·z² + k₄·z³

Fd = μ(z) · ż
μ(z) = d₀ + d₁·z
```

**Combined equation:**
```
F = k₁·z + k₂·z² + k₃·z³ + k₄·z⁴ + d₀·ż + d₁·z·ż
```

### Nonlinearity Comparison

| System | Higher-order coefficients | Behavior |
|---|---|---|
| Classical manikin | Only k₂ ≠ 0 | Near-linear |
| Human thorax | k₂, k₃, k₄ ≠ 0 | Nonlinear |
| Thielen manikin | k₂, k₃, k₄ ≠ 0 | Nonlinear (human-like) |

> "Our manikin, unlike typical manikins, shows a greater nonlinear relationship since the polynomial estimate of the force–displacement relationship has **three non-zero higher order components (k₂, k₃ and k₄)** while the typical manikin has only one higher order component (k₂)."

---

## Results (Figure 8)

Force-displacement curves at 5 cm depth (AHA guideline target):

| System | Force at 5 cm | Shape |
|---|---|---|
| Human thorax | ~700 N | Nonlinear, progressive |
| Classical manikin | ~600 N | Near-linear |
| Thielen manikin | ~200 N | Nonlinear but too soft |

**Key finding:** Their manikin achieves the correct nonlinear *shape* but with insufficient *stiffness*.

---

## Design Details

### Rib Cage
- Material: Polyoxymethylene (POM), 4mm thick
- Cut via laser engraver, heat-shaped
- Bolted to T1-T10 vertebrae of anatomical spine model
- Rationale: High stiffness, abrasion resistance, resilience to repeated load

### Respiratory System
| Component | Material | Specs |
|---|---|---|
| Lungs | PU memory foam | ρ = 45 kg/m³, silicone-coated |
| Bronchi | PVC | - |
| Trachea | Latex tube | ID = 2 cm |
| Airflow sensor | Honeywell AMW720P1 | In trachea |

### Cardiovascular System
| Component | Material | Specs |
|---|---|---|
| Ventricles | Latex balloons | 75 mL each (female reference) |
| Arteries | Latex tubing | ID = 1 cm |
| Heart wall | PE foam | ρ = 25 kg/m³ |
| Blood | Life/form simulation blood | - |
| Flow sensors | B.I.O-TECH Vision 2000 | In aortic & pulmonary arteries |

### Data Acquisition
- Arduino Uno microcontroller
- Processing software for real-time display
- Philips Q-CPR for force-displacement measurement

---

## Cardiac Output Results

At 120 CPM (AHA guideline):
- Total cardiac output: 1.65 L/min
- Left ventricle: 0.92 L/min
- Right ventricle: 0.73 L/min
- Air displacement: 2.7 L/min

Comparison:
- 48% lower than Fodden et al. (human Doppler measurement)
- 150% higher than Koeken et al. (physiological model, after scaling)

---

## Key Quotes

### On clinical need (p.2)
> "There is a key clinical demand for CPR manikins to **mimic human physiology** and monitor cardiac output, artificial ventilation and oxygen saturation in order to **provide feedback data for assessing CPR performance**."

### On fidelity relationship (p.6)
> "The novelty of this design is the anatomical design and construction of the manikin with the expectation that **improving physical fidelity increases functional fidelity** as showcased by Sawyer et al. in training simulators for intubation."

### On stiffness limitation (p.6)
> "However, the force required to achieve similar compression depths in humans is considerably higher. This indicates that **the stiffness of our manikin is low**."

### On material challenges (p.6)
> "The challenge herein is that the materials not only need to have **suitable material properties** but should also be **amiable to the rigours of manufacturing processes** such as laser cutting, heat shaping and injection moulding."

---

## Limitations (Stated)

1. Stiffness too low (less force needed than human thorax)
2. No valves in cardiovascular system
3. No connection between pulmonary and systemic circulations
4. Manufacturing constraints limited rib cage thickness
5. Higher density foams mimicking lung tissue unavailable

---

## Relevance to MST Paper

### VERY HIGH Relevance

1. **Directly supports mechanical fidelity concept:** Paper explicitly argues that anatomical/physical fidelity → functional/physiological fidelity

2. **Documents the linear vs nonlinear gap:** Classical manikins have linear F-D, humans have nonlinear F-D - this is exactly the "mechanical fidelity gap" we're characterizing

3. **Provides force-displacement model:** Gruben polynomial model could be used for our characterization methodology

4. **Names specific manikins as inadequate:** SimMan 3G and Apollo explicitly called out as not meeting fidelity requirements

5. **Dutch connection:** TU Eindhoven + Máxima Medisch Centrum - potential collaboration/citation network

### Quotable for Introduction

> "even the technologically most advanced manikins such as the SimMan 3G (Laerdal) and Apollo (CAE healthcare) do not fulfil all these requirements"

This directly supports I2 (no systematic benchmark exists) and the mechanical fidelity gap argument.

---

## References of Interest

| Ref | Citation | Potential Use |
|-----|---|---|
| 7 | Bankman et al. 1990, IEEE Trans Biomed Eng | Human chest mechanical parameters during CPR |
| 8 | Gruben et al. 1990, IEEE Trans Biomed Eng | Mechanical measurement system during CPR |
| 9 | Gruben et al. 1999, IEEE Trans Biomed Eng | Canine sternal F-D relationship |
| 18 | Tomlinson et al. 2007 | Compression force-depth (already have) |
| 15 | Martin et al. 2013 | "Physiological" infant manikin design |

---

## Cross-Reference

- Related: Tomlinson 2007 (nonlinearity), Nysæther 2008 (human stiffness)
- Claim registry: Supports I2, potentially new claim on linear vs nonlinear gap

---

*Extracted: 2026-01-21*

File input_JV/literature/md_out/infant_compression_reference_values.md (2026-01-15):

# Infant/Neonatal Chest Compression Reference Values

**Extracted:** 2026-01-15
**Purpose:** Human reference model for compression fidelity - MST paper Section 2.2

---

## Source 1: Japan Laser Study 2024 (Pediatr Crit Care Med) - **CRITICAL**

**Citation:** "Chest Compression Depth Targets in Critically Ill Infants and Children Measured With a Laser Distance Meter." Pediatr Crit Care Med. 2024.

**PMID:** [38602429](https://pubmed.ncbi.nlm.nih.gov/38602429/)
**DOI:** [10.1097/PCC.0000000000003509](https://doi.org/10.1097/PCC.0000000000003509)

### Sample
- **n = 555** critically ill patients <8 years
- **Setting:** Single-center PICU, Japan (May 2019 - May 2022)
- **Method:** Laser distance meter measured anterior-posterior chest diameter (APd)
- **Target:** 1/3 of APd (per guidelines)

### Age-Stratified Compression Depth Targets

| Age | Target Depth (cm) | IQR (cm) |
|-----|---|---|
| **0 months** | **2.7** | 2.5-2.9 |
| **2 months** | **2.9** | 2.7-3.2 |
| 3-5 months | 3.2 | 3.0-3.5 |
| 6-8 months | 3.4 | 3.2-3.6 |
| 9-11 months | 3.4 | 3.2-3.6 |
| 12-17 months | 3.6 | 3.4-3.8 |
| 18-23 months | 3.6 | 3.4-4.0 |
| 24-60 months | 4.0 | 3.5-4.2 |

### Critical Finding

**Current guidelines recommend 4 cm for infants** - but actual 1/3 APd measurements show:
- **49% of infants 0-2 months would be over-compressed** using 4cm target
- **45.5% of children 12-17 months would be over-compressed**

**Implication for manikin design:** Fixed 4cm depth target may not reflect physiological variation. Age-adjustable depth feedback needed.

---

## Source 2: 2025 AHA/AAP Neonatal Resuscitation Guidelines

**Citation:** "Part 5: Neonatal Resuscitation: 2025 American Heart Association and American Academy of Pediatrics Guidelines for CPR and ECC." Circulation. 2025.

**DOI:** [10.1161/CIR.0000000000001367](https://doi.org/10.1161/CIR.0000000000001367)
**Release Date:** October 22, 2025

### Compression Depth Recommendation

| Parameter | Recommendation |
|---|---|
| **Depth** | ~1/3 of chest AP diameter |
| **Absolute (infant)** | ~4 cm (1.5 inches) |
| **Rate** | 100-120 compressions/min |

### Key Changes from Previous Guidelines

1. **Two-finger technique ELIMINATED** - ineffective for achieving proper depth
2. **Approved techniques:**
   - Two thumbs-encircling hands (preferred)
   - One-hand technique (if cannot encircle chest)
3. **Ventilation rate:** 30-60 inflations/min (expanded from 40-60)
4. **Deferred cord clamping:** ≥60 seconds (increased from ≥30 sec)

### Compression Technique

> "The current international guidelines recommend neonatal resuscitation with the two thumb encircling method over the lower third of the sternum. Proper depth is approximately one-third of the anteroposterior diameter of the chest wall."

---

## Summary Table for MST Paper

### Infant Compression Reference Model

| Parameter | Value | Age | Source |
|---|---|-----|---|
| Target depth (0 mo) | 2.7 cm (2.5-2.9) | Newborn | Japan 2024 |
| Target depth (2 mo) | 2.9 cm (2.7-3.2) | 2 months | Japan 2024 |
| Target depth (6-11 mo) | 3.4 cm (3.2-3.6) | 6-11 months | Japan 2024 |
| Target depth (12-23 mo) | 3.6 cm (3.4-4.0) | 12-23 months | Japan 2024 |
| Guideline depth (infant) | ~4 cm | <1 year | AHA 2025 |
| Compression rate | 100-120/min | All ages | AHA 2025 |

### Key Observations for Manikin Design

1. **Guideline 4cm may overcompress young infants** - Japan data shows 2.7-2.9cm for 0-2 months
2. **Age-dependent targets** - significant variation from newborn (2.7cm) to toddler (4.0cm)
3. **Two-finger technique eliminated** - manikins should train two-thumb encircling method
4. **IQR shows individual variation** - ~0.4-0.6cm spread within age groups

---

## Source 3: SURV1VE Trial 2024 (Arch Dis Child Fetal Neonatal Ed)

**Citation:** "Sustained inflation and chest compression versus 3:1 compression:ventilation ratio during CPR of asphyxiated newborns." Arch Dis Child Fetal Neonatal Ed. 2024;109:608-615.

**DOI:** [10.1136/archdischild-2023-326383](https://doi.org/10.1136/archdischild-2023-326383)
**PMC:** [PMC11228189](https://pmc.ncbi.nlm.nih.gov/articles/PMC11228189/)

### Study Design
- **Sample:** 27 newborns (12 CC+SI, 15 standard 3:1)
- **Setting:** 4 hospitals in Canada and Austria
- **Note:** Terminated early (target was 218) due to funding/regulatory issues

### Interventions Compared

| Parameter | CC+SI | Standard 3:1 |
|---|---|---|
| Compressions | 90/min continuous | 3:1 ratio with ventilations |
| Inflation pressure | 25-30 cmH₂O sustained | Standard PPV |
| PEEP | 5-8 cmH₂O | Standard |

### Outcomes (Not statistically significant due to small n)

| Outcome | CC+SI | 3:1 C:V | p-value |
|---|---|---|---|
| Time to ROSC | 90 (60-270) s | 615 (174-780) s | 0.0502 |
| Mortality | 2/11 (18.2%) | 8/14 (57.1%) | NS |

### Relevance to Manikin Design
- Compression rate of 90/min for CC+SI differs from standard 100-120/min
- Continuous compressions (no pause for ventilation) is alternative approach
- **Note:** Authors caution against clinical use outside research settings

---

## Source 4: Novel CC Technique 2025 (Children)

**Citation:** "Evaluating Novel Chest Compression Technique in Infant CPR: Enhancing Efficacy and Reducing Rescuer Fatigue." Children. 2025;12(3):346.

**DOI:** [10.3390/children12030346](https://doi.org/10.3390/children12030346)
**PMC:** [PMC11940949](https://pmc.ncbi.nlm.nih.gov/articles/PMC11940949/)

### Study Design
- **Sample:** 34 medical students
- **Design:** Randomized crossover trial
- **Duration:** 2-minute compression cycles with 15-min rest

### Technique Description
Novel technique (nT): Dominant hand with index finger flexed at proximal interphalangeal joint. External (dorsal) surface of middle phalanx contacts sternum, thumb supports from opposite side.

### Compression Adequacy Comparison

| Technique | Adequate Rate | Mean Depth (mm) |
|---|---|---|
| **Novel (nT)** | **92.4%** | 42.9 |
| Two-Thumb (TTHT) | 78.6% | 44.2 |
| Two-Finger (TFT) | 65.2% | 38.6 |

### Rescuer Fatigue (Lower = Better)

| Measure | nT | TTHT | TFT |
|---|-----|---|-----|
| Fatigue (RPE) | 3.63 | 4.06 | 6.63 |
| Hand Pain (NRS) | 3.48 | 4.36 | 6.93 |

### Key Finding
Novel technique "bridges the gap, offering TTHT-like depth with TFT-like adaptability" - promising for single-rescuer scenarios.

### Relevance to Manikin Design
- Target depth ~43mm for adequate compression on manikin
- Technique comparison data useful for training feedback design
- Fatigue metrics important for extended CPR scenarios

---

## Evidence Gap Identified

**No published data on:**
- Infant manikin chest stiffness values
- Force-depth relationship in infant manikins
- Comparison of manikin compression mechanics to human infant data

**MST paper contribution:** Characterize infant manikin compression mechanics and compare to Japan 2024 reference values.

---

## Sources

- [Japan Laser Study 2024 - PubMed](https://pubmed.ncbi.nlm.nih.gov/38602429/) **[WEB VERIFIED]**
- [2025 AHA Guidelines - Circulation](https://doi.org/10.1161/CIR.0000000000001367) **[WEB VERIFIED]**
- [AHA News Release](https://newsroom.heart.org/news/updated-cpr-guidelines-released-for-pediatric-and-neonatal-emergency-care-and-resuscitation)
- [SURV1VE Trial 2024 - PMC](https://pmc.ncbi.nlm.nih.gov/articles/PMC11228189/) **[WEB VERIFIED]**
- [Novel CC Technique 2025 - PMC](https://pmc.ncbi.nlm.nih.gov/articles/PMC11940949/) **[WEB VERIFIED]**

---

*Extracted: 2026-01-15*
*Updated: 2026-01-15 - Added SURV1VE Trial and Novel CC Technique*
*Status: [WEB VERIFIED] - PDF download recommended for Japan study*

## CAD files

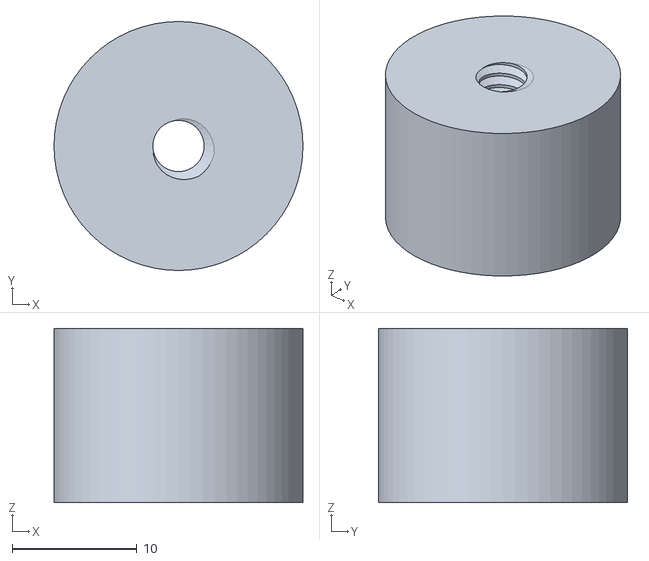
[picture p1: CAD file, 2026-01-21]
hardware/Calibration extension for Compression Actuator Load Cell.stl
20.0 x 20.0 x 14.0

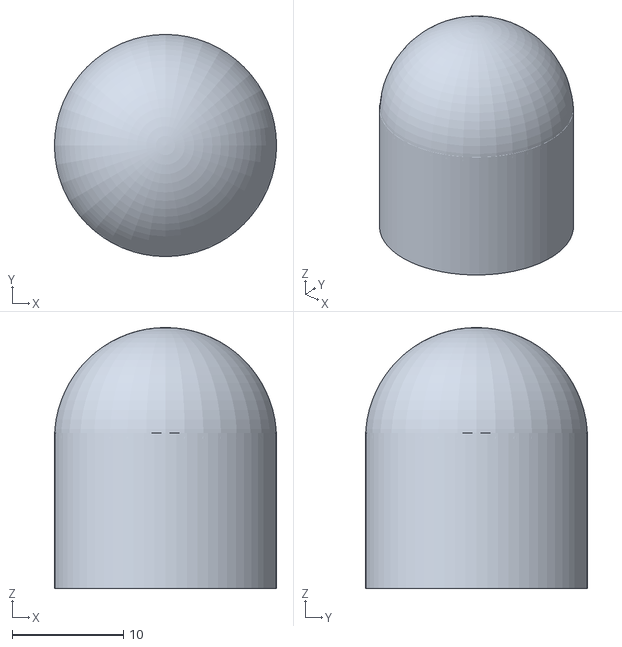
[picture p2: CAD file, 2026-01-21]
hardware/Compression Actuator extension.stl
20.0 x 20.0 x 23.5

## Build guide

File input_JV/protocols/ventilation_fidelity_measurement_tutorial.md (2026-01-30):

# Ventilation Fidelity Measurement Tutorial

**Purpose:** Step-by-step guide to measuring infant manikin ventilation mechanics and comparing against human reference data.

**Target Audience:** Researchers implementing the mechanical fidelity assessment protocol

**Last Updated:** 2026-01-30

---

## Table of Contents

1. [Overview](#1-overview)
2. [Equipment Required](#2-equipment-required)
3. [The Model](#3-the-model)
4. [Hardware Setup](#4-hardware-setup)
5. [Calibration](#5-calibration)
6. [Measurement Protocol](#6-measurement-protocol)
7. [Data Analysis](#7-data-analysis)
8. [Fidelity Scoring](#8-fidelity-scoring)
9. [Troubleshooting](#9-troubleshooting)
10. [Reference Data](#10-reference-data)

---

## 1. Overview

### What We're Measuring

We characterize infant CPR manikin "lungs" using two key parameters:

| Parameter | Symbol | Unit | What It Tells Us |
|---|---|---|---|
| **Compliance** | C | mL/kPa | How easily the lung expands (volume per unit pressure) |
| **Resistance** | R | kPa/L/s | How hard it is to push air through the airway |

### The Goal

Compare manikin C and R values against human infant reference data (Huang 2016) to quantify **mechanical fidelity** — how closely the manikin mimics real infant respiratory mechanics.

### Why It Matters

- A manikin with wrong C/R teaches incorrect ventilation technique
- Too compliant → trainee uses too little pressure → underventilation in real infant
- Too stiff → trainee uses too much pressure → barotrauma risk in real infant

---

## 2. Equipment Required

### Primary Sensors

| Component | Model | Range | Purpose |
|---|---|---|---|
| Pressure sensor | Bronkhorst EL-PRESS P-502C | 0–100 mbar | Airway pressure (Paw) |
| Flow sensor | Bronkhorst MFM | 0–2 ln/min* | Airflow (Q) |
| Backup pressure | MPXV5010GP | 0–10 kPa | Redundancy / blocked airway |

*Verify flow range is appropriate for infant tidal volumes (~20-50 mL at ~10-30 breaths/min)

### Pneumatic Supply (for Continuous Flow Method)

| Component | Model | Range | Purpose |
|---|---|---|---|
| Supply regulator | Festo MS2-LFR-QS6-D6 | 0.5–7 bar | Reduce lab pressure, filter |
| Pressure controller | Bronkhorst EL-PRESS | 0–100 mbar | Precision mbar control |

**See Section 4.3 for complete pneumatic chain setup.**

### Manual Ventilation Source (Alternative)

| Option | Pros | Cons |
|---|---|---|
| Calibrated syringe (50 mL) | Precise volume control | Manual, slower |
| Neopuff / T-piece | Realistic, pressure-controlled | Less volume precision |
| Self-inflating bag | Realistic training device | Variable delivery |

**Recommended:** Use continuous flow method (Section 6.5) for characterization, then validate with clinical devices.

### Data Acquisition

| Component | Purpose |
|---|---|
| Microcontroller (STM32/Arduino) | Sensor interface |
| ADC (if needed) | Analog sensor digitization |
| PC with Python/MATLAB | Data logging and analysis |

### Consumables & Accessories

- Tubing (medical grade, ID ~4-6 mm for infant)
- Connectors / adapters for manikin airway
- Leak-test equipment (soap solution or electronic leak detector)
- Reference masses for pressure calibration (water column)

---

## 3. The Model

### Single-Compartment RC Model

The respiratory system behaves like an electrical RC circuit:

```
                    R (resistance)
    ┌───────────────/\/\/\───────────────┐
    │                                     │
    │                                     │
  P_aw                                   ─┴─
(pressure)                               ─┬─  C (compliance)
    │                                     │
    │                                     │
    └─────────────────────────────────────┘
                                         GND
```

### Equation of Motion

```
P_airway = P_elastic + P_resistive

P_airway = V/C + R·Q

Where:
  P_airway = pressure at airway opening (kPa)
  V        = volume in lung above FRC (mL)
  C        = compliance (mL/kPa)
  Q        = flow rate (L/s)
  R        = resistance (kPa/L/s)
```

### What This Means Practically

- **At zero flow (Q = 0):** P = V/C → measure compliance
- **During flow:** P increases by R·Q → measure resistance
- **Compliance** = how much the lung stretches per unit pressure
- **Resistance** = pressure needed to drive airflow

---

## 4. Hardware Setup

### 4.1 System Diagram

```
┌─────────────────┐
│  Ventilation    │
│  Source         │
│  (syringe/bag)  │
└────────┬────────┘
         │
         ▼
┌─────────────────┐
│  Flow Sensor    │──────► Flow signal (Q)
│  (MFM)          │
└────────┬────────┘
         │
         ▼
┌─────────────────┐
│  Pressure Tap   │──────► Pressure signal (P)
│  (T-connector)  │
└────────┬────────┘
         │
         ▼
┌─────────────────┐
│  Manikin        │
│  Airway/Lung    │
└─────────────────┘
```

### 4.2 Connection Details

1. **Flow sensor placement:** Proximal to manikin (measure all delivered flow)
2. **Pressure tap:** Between flow sensor and manikin airway
3. **Leak check:** Critical — any leak invalidates compliance measurement

### 4.3 Pneumatic Supply Chain (for Continuous Flow Method)

For the continuous flow measurement method (Section 6.5), controlled low-pressure air delivery is required.

**System diagram:**

```
┌──────────────────┐
│  Compressed Air  │  (Lab supply, ~4-8 bar)
│  Source          │
└────────┬─────────┘
         │
         ▼
┌──────────────────┐
│  MS2-LFR-QS6-D6  │  Festo precision regulator
│  (0.5–7 bar out) │  → reduces to 1-2 bar working pressure
└────────┬─────────┘
         │
         ▼
┌──────────────────┐
│  EL-PRESS P-502C │  Bronkhorst electronic pressure controller
│  (0–100 mbar)    │  → fine control for 10-50 mbar output
└────────┬─────────┘
         │
         ▼
┌──────────────────┐
│  MFM             │  Bronkhorst mass flow meter
│  (0–2 ln/min)    │  → measures actual delivered flow
└────────┬─────────┘
         │
         ▼
┌──────────────────┐
│  Manikin Airway  │
└──────────────────┘
```

**Component specifications:**

| Component | Model | Range | Purpose |
|---|---|---|---|
| Supply regulator | Festo MS2-LFR-QS6-D6 | 0.5–7 bar out | Clean, stable supply pressure |
| Pressure controller | Bronkhorst EL-PRESS P-502C | 0–100 mbar | Precision mbar-level control |
| Flow meter | Bronkhorst MFM | 0–2 ln/min | SI-traceable flow measurement |

**Pressure cascade:**
- Lab supply: ~5 bar
- After MS2-LFR: ~1 bar (reduces supply, filters)
- After EL-PRESS: 10–50 mbar (final output to manikin)

**Why two stages?**

The EL-PRESS requires stable upstream pressure to regulate accurately in the mbar range. The Festo MS2-LFR provides this by:
1. Reducing high supply pressure to manageable level
2. Filtering particulates (protects downstream components)
3. Damping pressure fluctuations from supply

**Important:** The MS2-LFR minimum output (500 mbar) is too high for direct manikin use — you need the EL-PRESS for final mbar-level control.

### 4.4 Sensor Wiring

**EL-PRESS P-502C:**
- Interface: RS232 or Modbus (check your unit)
- Power: Per Bronkhorst specs
- Output: Digital pressure reading in mbar
- Setpoint: Digital or analog (for continuous flow control)

**MFM (Mass Flow Meter):**
- Interface: RS232 or analog 0-5V
- Calibration: Factory calibrated, SI-traceable
- Output: Flow in ln/min (normalize to L/s)

### 4.5 Manikin Interface

Different manikins have different airway configurations:

| Manikin Type | Airway Interface | Notes |
|---|---|---|
| Laerdal Baby Anne | 15 mm connector | Standard pediatric |
| Simulaids infant | Proprietary | May need adapter |
| Prestan infant | 15 mm connector | Check for leak points |

**Tip:** Create a universal adapter plate with sealed connections.

---

## 5. Calibration

### 5.1 Pressure Sensor Calibration

**Zero calibration:**
1. Open sensor to atmosphere
2. Record reading → should be 0 mbar (±0.1 mbar)
3. If offset, record and subtract in software

**Span calibration:**
1. Connect to water column manometer
2. Apply known pressures: 10, 20, 50, 100 cmH₂O
3. Record sensor output at each point
4. Fit linear calibration: P_true = a × P_sensor + b

**Conversion:** 1 cmH₂O = 0.981 mbar ≈ 0.098 kPa

### 5.2 Flow Sensor Calibration

**Volume verification:**
1. Connect calibrated syringe (50 mL) to flow sensor
2. Deliver full syringe volume at steady rate (~1-2 seconds)
3. Integrate flow signal: V = ∫Q dt
4. Compare integrated volume to syringe volume
5. Should match within ±5%

**If using SDP810 (differential pressure):**
- Requires orifice plate or venturi calibration
- Flow = k × √(ΔP) — calibrate k with known flows

### 5.3 System Leak Test

**Critical step — do before every measurement session:**

1. Seal manikin airway (plug or clamp)
2. Deliver 30 mL with syringe
3. Hold for 10 seconds
4. Monitor pressure — should remain stable (±5% drop max)
5. If pressure drops significantly → find and fix leak

---

## 6. Measurement Protocol

### 6.1 Preparation

- [ ] Calibrate all sensors (Section 5)
- [ ] Leak test system
- [ ] Record ambient conditions (temperature, humidity)
- [ ] Document manikin model, serial number, condition

### 6.2 Compliance Measurement (Quasi-Static Method)

This method minimizes resistance effects by using slow inflation.

**Procedure:**

1. **Connect** manikin to measurement system
2. **Zero** pressure sensor with airway open
3. **Deliver volume in steps:**

   | Step | Volume (mL) | Hold time (s) |
   |------|-------------|---------------|
   | 1 | 10 | 2 |
   | 2 | 20 | 2 |
   | 3 | 30 | 2 |
   | 4 | 40 | 2 |
   | 5 | 50 | 2 |

4. **Record** plateau pressure at each step (after ~1s stabilization)
5. **Release** volume, let pressure return to zero
6. **Repeat** 3 times for reproducibility

**Data recording format:**

```csv
trial,volume_mL,pressure_plateau_kPa,time_s
1,10,0.12,2.1
1,20,0.25,2.0
1,30,0.38,2.1
...
```

### 6.3 Resistance Measurement (Dynamic Method)

**Procedure:**

1. **Deliver** 30 mL at controlled rate (~0.5 seconds, Q ≈ 60 mL/s = 3.6 L/min)
2. **Record** continuously: P(t), Q(t)
3. **Identify:**
   - P_peak = maximum pressure during inflation
   - P_plateau = pressure 0.5s after flow stops
   - Q_mean = average flow during inflation

4. **Calculate:**
   ```
   R = (P_peak - P_plateau) / Q_mean
   ```

5. **Repeat** 5 times, report mean ± SD

### 6.4 Alternative: Single-Breath Analysis

If equipment supports high-speed acquisition (>100 Hz):

1. Deliver single tidal breath (~30 mL over 0.5s)
2. Record P, Q continuously
3. Compute V by integrating Q
4. Fit equation: P = V/C + R·Q using least squares
5. Extract C and R from fit parameters

**Python pseudocode:**
```python
from scipy.optimize import curve_fit

def model(X, C, R):
    V, Q = X
    return V/C + R*Q

# X = [volume_array, flow_array]
# P = pressure_array
popt, pcov = curve_fit(model, [V, Q], P)
C_fit, R_fit = popt
```

### 6.5 Continuous Flow Method (Recommended)

This method extracts both C and R from a single measurement by applying constant flow.

**Principle:**

With constant flow Q, the equation of motion becomes:
```
P(t) = V(t)/C + R·Q = (Q·t)/C + R·Q
```

This is a linear equation: **P(t) = (Q/C)·t + R·Q**

- **Slope** = Q/C → C = Q/slope
- **Intercept** = R·Q → R = intercept/Q

**Procedure:**

1. **Set constant flow** using EL-PRESS controlled regulator (see Section 4.3)
2. **Recommended flow rate:** 100–200 mL/min (1.7–3.3 mL/s)
   - Slow enough to avoid excessive R·Q pressure contribution
   - Fast enough to reach target volume in reasonable time
3. **Start flow** and record P(t) at ≥10 Hz
4. **Continue** until target volume reached (e.g., 30–50 mL)
5. **Stop flow** and record plateau pressure for verification
6. **Plot** P vs t during inflation phase
7. **Fit linear regression:** P = m·t + b

**Analysis:**

```
Given: Q = 0.003 L/s (180 mL/min)
       m = 0.04 kPa/s (slope from regression)
       b = 0.02 kPa (intercept)

Calculate:
  C = Q / m = 0.003 / 0.04 = 0.075 L/kPa = 75 mL/kPa
  R = b / Q = 0.02 / 0.003 = 6.7 kPa/L/s
```

**Python pseudocode:**
```python
import numpy as np
from scipy.stats import linregress

# Data from inflation phase
time = np.array([...])      # seconds
pressure = np.array([...])  # kPa
Q = 0.003                   # L/s (constant flow)

# Linear regression
slope, intercept, r_value, p_value, std_err = linregress(time, pressure)

# Extract parameters
C = Q / slope * 1000  # mL/kPa
R = intercept / Q     # kPa/L/s

print(f"Compliance: {C:.1f} mL/kPa")
print(f"Resistance: {R:.2f} kPa/L/s")
print(f"R² = {r_value**2:.3f}")
```

**Advantages:**
- Both C and R from single measurement
- Less sensitive to operator technique
- Continuous recording captures nonlinearities if present
- Automation-friendly (reproducible flow)

**Pressure range expected:**

For infant manikins with typical C = 50–150 mL/kPa and R = 4–8 kPa/L/s:
- At Q = 3 mL/s, R·Q = 4–8 × 0.003 = 0.012–0.024 kPa (1.2–2.4 mbar)
- At V = 50 mL, V/C = 50/50 to 50/150 = 0.33–1.0 kPa (33–100 mbar)
- **Total: ~10–50 mbar typical, max ~100 mbar**

---

## 7. Data Analysis

### 7.1 Compliance Calculation

**From quasi-static data:**

1. Plot Volume (y-axis) vs Pressure (x-axis)
2. Fit linear regression: V = C × P + b
3. **Compliance C = slope** (mL/kPa)
4. Intercept b should be ≈0 (if not, check for trapped gas)

**Example calculation:**

| V (mL) | P (kPa) |
|---|---|
| 10 | 0.12 |
| 20 | 0.24 |
| 30 | 0.37 |
| 40 | 0.49 |
| 50 | 0.61 |

Linear fit: V = 81.3 × P + 0.2

**C = 81.3 mL/kPa**

### 7.2 Resistance Calculation

**From dynamic data:**

```
R = (P_peak - P_plateau) / Q

Example:
  P_peak = 0.85 kPa
  P_plateau = 0.37 kPa
  Q = 0.060 L/s (60 mL/s)

  R = (0.85 - 0.37) / 0.060 = 8.0 kPa/L/s
```

### 7.3 Uncertainty Estimation

**For compliance:**
- Repeat measurement 3× → calculate SD
- Report: C = mean ± SD (mL/kPa)

**For resistance:**
- Repeat measurement 5× → calculate SD
- Report: R = mean ± SD (kPa/L/s)

**Combined uncertainty:**
```
u_C = √(u_V² + u_P²) × C
u_R = √(u_P² + u_Q²) × R
```

---

## 8. Fidelity Scoring

### 8.1 Reference Envelope (Huang 2016)

Select reference based on manikin's target population:

| Target Age | C (mL/kPa) | R (kPa/L/s) |
|---|---|---|
| **Term newborn (0-6 mo)** | 78 ± 46 | 6.4 (5.0–8.2) |
| **Infant (6-12 mo)** | 124 ± 51 | 5.1 (3.9–7.0) |
| **Infant (12-18 mo)** | 141 ± 45 | 4.2 (3.2–6.1) |
| **Toddler (18-24 mo)** | 171 ± 50 | 3.7 (2.8–4.7) |

### 8.2 Fidelity Index Calculation

**Method 1: Envelope inclusion (binary)**

```
Fidelity_C = 1 if (C_ref - SD) ≤ C_manikin ≤ (C_ref + SD), else 0
Fidelity_R = 1 if R_25th ≤ R_manikin ≤ R_75th, else 0
```

**Method 2: Normalized deviation**

```
δ_C = |C_manikin - C_ref| / C_ref
δ_R = |R_manikin - R_ref| / R_ref

Fidelity = 1 - (δ_C + δ_R) / 2

Where Fidelity ∈ [0, 1], higher = better
```

**Method 3: Z-score based**

```
Z_C = (C_manikin - C_mean) / C_SD
Z_R = (R_manikin - R_median) / (R_75th - R_25th)

Fidelity_C = max(0, 1 - |Z_C|/2)
Fidelity_R = max(0, 1 - |Z_R|/2)

Combined Fidelity = (Fidelity_C + Fidelity_R) / 2
```

### 8.3 Reporting Format

```
MANIKIN FIDELITY REPORT
=======================
Model: [Manikin name]
Serial: [S/N]
Target population: Term newborn (0-6 months)
Test date: 2026-XX-XX

MEASURED VALUES
---------------
Compliance (C): 65.2 ± 3.1 mL/kPa (n=3)
Resistance (R): 7.8 ± 0.4 kPa/L/s (n=5)

REFERENCE VALUES (Huang 2016)
-----------------------------
Compliance: 78 ± 46 mL/kPa
Resistance: 6.4 (5.0-8.2) kPa/L/s

FIDELITY ASSESSMENT
-------------------
Compliance: WITHIN envelope (Z = -0.28)
Resistance: WITHIN envelope (Z = +0.52)

Combined Fidelity Index: 0.80 / 1.00

INTERPRETATION
--------------
This manikin demonstrates acceptable mechanical fidelity
for term newborn ventilation training.
```

---

## 9. Troubleshooting

### Problem: Pressure doesn't stabilize

**Possible causes:**
- Leak in system → redo leak test
- Manikin lung still expanding → wait longer
- Temperature equilibration → let system settle

### Problem: Compliance too high (lung too soft)

**Check:**
- Is the manikin lung properly installed?
- Is there a hole or tear in the lung?
- Is the chest wall properly secured?

### Problem: Compliance too low (lung too stiff)

**Check:**
- Is the airway blocked?
- Is there water/debris in the lung?
- Is the manikin designed for a different age group?

### Problem: Resistance too high

**Check:**
- Airway obstruction (tongue, foreign body)
- Kinked tubing
- Narrow airway adapter

### Problem: Variable measurements

**Check:**
- Inconsistent syringe delivery technique
- Temperature fluctuations
- Sensor drift → recalibrate

---

## 10. Reference Data

### Human Infant Reference (Huang 2016)

**Population:** Term infants (GA ≥37 weeks), n=205, Southeast China

| Age (postnatal) | n | C (mL/kPa) | R (kPa/L/s) |
|---|---|---|---|
| 1–24 weeks | 84 | 77.95 ± 46.16 | 6.39 (5.00–8.15) |
| 25–48 weeks | 35 | 123.51 ± 50.64 | 5.11 (3.88–6.97) |
| 49–72 weeks | 36 | 141.17 ± 44.75 | 4.20 (3.17–6.11) |
| 73–96 weeks | 50 | 170.58 ± 50.14 | 3.74 (2.78–4.72) |

**Units:**
- C = compliance in mL/kPa (Crs from single occlusion technique)
- R = resistance in kPa/L/s (Rrs, median with P25-P75)

### Unit Conversions

| From | To | Multiply by |
|---|----|---|
| mbar | kPa | 0.1 |
| cmH₂O | kPa | 0.0981 |
| cmH₂O | mbar | 0.981 |
| L/min | L/s | 1/60 |
| mL/cmH₂O | mL/kPa | 10.2 |

### Key Literature

1. Huang J et al. (2016) J Thorac Dis 8(3):513-519
2. Stoecklin B et al. (2024) J Appl Physiol 136(6):1499-1506
3. Papastamelos C et al. (1995) J Appl Physiol 78(1):179-184

---

## Appendix A: Quick Reference Card

```
VENTILATION FIDELITY MEASUREMENT - QUICK REFERENCE
===================================================

SETUP CHECKLIST
□ Pressure sensor zeroed
□ Flow sensor calibrated (±5% volume)
□ System leak tested (<5% pressure drop in 10s)
□ Manikin documented (model, S/N)
□ Pneumatic chain: MS2-LFR → EL-PRESS → MFM → Manikin

METHOD 1: CONTINUOUS FLOW (Recommended)
1. Set constant flow 100-200 mL/min via EL-PRESS
2. Record P(t) during inflation
3. Plot P vs t → linear fit: P = m·t + b
4. C = Q/m, R = b/Q
5. Expect P range: 10-50 mbar typical

METHOD 2: QUASI-STATIC (Manual, C only)
1. Deliver 10, 20, 30, 40, 50 mL steps
2. Hold 2s each, record P_plateau
3. Plot V vs P → slope = C
4. Repeat 3×

METHOD 3: DYNAMIC (Manual, R only)
1. Deliver 30 mL in 0.5s
2. Record P_peak and P_plateau
3. R = (P_peak - P_plateau) / Q
4. Repeat 5×

TARGET VALUES (term newborn)
C: 78 ± 46 mL/kPa
R: 6.4 (5.0-8.2) kPa/L/s

PRESSURE RANGE (infant manikins)
Typical: 10-50 mbar
Maximum: ~100 mbar
```

---

*Document created: 2026-01-30*
*Author: Claude Code + JK*
*Project: MST Paper — Mechanical Fidelity of Infant CPR Manikins*

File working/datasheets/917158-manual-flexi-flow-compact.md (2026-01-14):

# 917158-manual-flexi-flow-compact

## Page 1

FLEXI-FLOW™ Compact
Doc. no.: 9.17.158 rev. I     Date: 22-12-2025
Instruction Manual
ATTENTION
Please read this document carefully before installing and operating the product.
Not following the guidelines could result in personal injury and/or damage to the equipment.
Keep this document for future reference.

## Page 2

Bronkhorst®
Instruction Manual FLEXI-FLOW™ Compact
9.17.158I
2
Copyright
© 2025 Bronkhorst High-Tech B.V. - All rights reserved.
Bronkhorst® is a registered trademark of Bronkhorst High-Tech B.V.
All trademarks are the property of their respective owners.
Disclaimer
The illustrations in this document serve to provide general notices regarding correct operation and may differ from the actual
product.
Bronkhorst High-Tech B.V. reserves the right to modify or improve its products and documentation without notice. Prior to work,
check whether a newer version of this document is available on the Bronkhorst website.
Symbols in this document
Important information. Disregarding this information could increase the risk of damage to the equipment, or the risk
of personal injuries.
Tips, useful information, attention points. This will facilitate the use of the product and/or contribute to its optimal
performance.
Additional information available in the referenced documentation, on the indicated website(s) or from your
Bronkhorst representative.
Service
If you have a question about a product or if you find the product does not meet the specifications as
ordered, do not hesitate to contact your Bronkhorst representative. To enable us to help you quickly
and effectively, make sure to have the serial number (SN) ready whenever seeking contact with your
Bronkhorst representative about a specific item.
For current information about Bronkhorst® and worldwide service addresses, please visit our website:
 www.bronkhorst.com
Do you have any questions about our products? Our Sales department will gladly assist you selecting the right product for your
application. Contact sales by e-mail:
 sales@bronkhorst.com
For after-sales questions, help and guidance, our Customer Care department is available by e-mail:
 aftersales@bronkhorst.com
No matter the time zone, our experts within the Customer Care department are available to answer your request immediately
or take appropriate further action. Our experts can be reached at:
 +31 859 02 18 66
Bronkhorst High-Tech B.V.
Nijverheidsstraat 1A
NL-7261 AK Ruurlo
The Netherlands

## Page 3

Bronkhorst®
Instruction Manual FLEXI-FLOW™ Compact
9.17.158I
3
Warranty
For information about the warranty and the general terms of delivery, please visit www.bronkhorst.com/terms-andconditions/
Receipt of equipment
· Check that the outer packaging and its contents have not been damaged during transport. If the outer packaging or its
contents are damaged, the local carrier must be informed immediately regarding his liability, if so required. At the same time
a report should be submitted to your Bronkhorst representative.
· If the product is damaged, it should not be put into service. In that case, contact your Bronkhorst representative for service.
· Check the packing list to ensure that you received all items included in the scope of delivery.
· Do not discard spare or replacement parts.
· See Removal and return instructions
 for information about return shipment procedures.
Equipment storage
· The equipment should be stored in its original package in a climate controlled storage location.
· Care should be taken not to subject the equipment to excessive temperatures or humidity.
· See technical specifications
 for information about required storage conditions.
26
11

## Page 4

Bronkhorst®
Instruction Manual FLEXI-FLOW™ Compact
9.17.158I
4

## Page 5

Bronkhorst®
Instruction Manual FLEXI-FLOW™ Compact
9.17.158I
5
Table of contents
. . . . . . . . . . . . . . . . . . . . . . . . . . . . . . . . . . . . . . . . . . . . . . . . . . . . . . . . . . . . . . . . . . . . . . . . . . . . . . . . . . . . . . . . . . . . . . . . . . . . . . . 7
1
General information
. . . . . . . . . . . . . . . . . . . . . . . . . . . . . . . . . . . . . . . . . . . . . . . . . . . . . . . . . . . . . . . . . . . . . . . . . . . . . . . . . . . . . . . . . . . . . . . . . . . . . . . . . . . . . . 7
1.1
Scope of this document
. . . . . . . . . . . . . . . . . . . . . . . . . . . . . . . . . . . . . . . . . . . . . . . . . . . . . . . . . . . . . . . . . . . . . . . . . . . . . . . . . . . . . . . . . . . . . . . . . . . . . . . . . . . . . . 7
1.2
Declaration of conformity
. . . . . . . . . . . . . . . . . . . . . . . . . . . . . . . . . . . . . . . . . . . . . . . . . . . . . . . . . . . . . . . . . . . . . . . . . . . . . . . . . . . . . . . . . . . . . . . . . . . . . . . . . . . . . . 7
1.3
Intended use
. . . . . . . . . . . . . . . . . . . . . . . . . . . . . . . . . . . . . . . . . . . . . . . . . . . . . . . . . . . . . . . . . . . . . . . . . . . . . . . . . . . . . . . . . . . . . . . . . . . . . . . . . . . . . . 8
1.4
Product overview
. . . . . . . . . . . . . . . . . . . . . . . . . . . . . . . . . . . . . . . . . . . . . . . . . . . . . . . . . . . . . . . . . . . . . . . . . . . . . . . . . . . . . . . . . . . . . . . . . . . . . . . . . . . . . . 10
1.5
Product features
. . . . . . . . . . . . . . . . . . . . . . . . . . . . . . . . . . . . . . . . . . . . . . . . . . . . . . . . . . . . . . . . . . . . . . . . . . . . . . . . . . . . . . . . . . . . . . . . . . . . . . . . . . . . . . 10
1.5.1
Offline/parallel configuration
. . . . . . . . . . . . . . . . . . . . . . . . . . . . . . . . . . . . . . . . . . . . . . . . . . . . . . . . . . . . . . . . . . . . . . . . . . . . . . . . . . . . . . . . . . . . . . . . . . . . . . . . . . . . . . 10
1.5.2
NAMUR instrument status
. . . . . . . . . . . . . . . . . . . . . . . . . . . . . . . . . . . . . . . . . . . . . . . . . . . . . . . . . . . . . . . . . . . . . . . . . . . . . . . . . . . . . . . . . . . . . . . . . . . . . . . . . . . . . . 10
1.5.3
Multi-parameter functionality
. . . . . . . . . . . . . . . . . . . . . . . . . . . . . . . . . . . . . . . . . . . . . . . . . . . . . . . . . . . . . . . . . . . . . . . . . . . . . . . . . . . . . . . . . . . . . . . . . . . . . . . . . . . . . . 10
1.5.4
On-board FLUIDAT® database
. . . . . . . . . . . . . . . . . . . . . . . . . . . . . . . . . . . . . . . . . . . . . . . . . . . . . . . . . . . . . . . . . . . . . . . . . . . . . . . . . . . . . . . . . . . . . . . . . . . . . . . . . . . . . . 10
1.5.5
Multi-channel systems
. . . . . . . . . . . . . . . . . . . . . . . . . . . . . . . . . . . . . . . . . . . . . . . . . . . . . . . . . . . . . . . . . . . . . . . . . . . . . . . . . . . . . . . . . . . . . . . . . . . . . . . . . . . . . . 11
1.6
Documentation
. . . . . . . . . . . . . . . . . . . . . . . . . . . . . . . . . . . . . . . . . . . . . . . . . . . . . . . . . . . . . . . . . . . . . . . . . . . . . . . . . . . . . . . . . . . . . . . . . . . . . . . . . . . . . . 12
1.7
Safety notes
. . . . . . . . . . . . . . . . . . . . . . . . . . . . . . . . . . . . . . . . . . . . . . . . . . . . . . . . . . . . . . . . . . . . . . . . . . . . . . . . . . . . . . . . . . . . . . . . . . . . . . . 14
2
Installation
. . . . . . . . . . . . . . . . . . . . . . . . . . . . . . . . . . . . . . . . . . . . . . . . . . . . . . . . . . . . . . . . . . . . . . . . . . . . . . . . . . . . . . . . . . . . . . . . . . . . . . . . . . . . . . 14
2.1
Product specifications
. . . . . . . . . . . . . . . . . . . . . . . . . . . . . . . . . . . . . . . . . . . . . . . . . . . . . . . . . . . . . . . . . . . . . . . . . . . . . . . . . . . . . . . . . . . . . . . . . . . . . . . . . . . . . . 14
2.1.1
Pressure rating
. . . . . . . . . . . . . . . . . . . . . . . . . . . . . . . . . . . . . . . . . . . . . . . . . . . . . . . . . . . . . . . . . . . . . . . . . . . . . . . . . . . . . . . . . . . . . . . . . . . . . . . . . . . . . . 14
2.1.2
Bluetooth certification
. . . . . . . . . . . . . . . . . . . . . . . . . . . . . . . . . . . . . . . . . . . . . . . . . . . . . . . . . . . . . . . . . . . . . . . . . . . . . . . . . . . . . . . . . . . . . . . . . . . . . . . . . . . . . . 14
2.2
Mounting
. . . . . . . . . . . . . . . . . . . . . . . . . . . . . . . . . . . . . . . . . . . . . . . . . . . . . . . . . . . . . . . . . . . . . . . . . . . . . . . . . . . . . . . . . . . . . . . . . . . . . . . . . . . . . . 15
2.2.1
Piping requirements
. . . . . . . . . . . . . . . . . . . . . . . . . . . . . . . . . . . . . . . . . . . . . . . . . . . . . . . . . . . . . . . . . . . . . . . . . . . . . . . . . . . . . . . . . . . . . . . . . . . . . . . . . . . . . . 15
2.2.2
Fluid connection
. . . . . . . . . . . . . . . . . . . . . . . . . . . . . . . . . . . . . . . . . . . . . . . . . . . . . . . . . . . . . . . . . . . . . . . . . . . . . . . . . . . . . . . . . . . . . . . . . . . . . . . . . . . . . . 15
2.2.3
Preventing pressure shocks
. . . . . . . . . . . . . . . . . . . . . . . . . . . . . . . . . . . . . . . . . . . . . . . . . . . . . . . . . . . . . . . . . . . . . . . . . . . . . . . . . . . . . . . . . . . . . . . . . . . . . . . . . . . . . . 16
2.3
Electrical connection
. . . . . . . . . . . . . . . . . . . . . . . . . . . . . . . . . . . . . . . . . . . . . . . . . . . . . . . . . . . . . . . . . . . . . . . . . . . . . . . . . . . . . . . . . . . . . . . . . . . . . . . . . . . . . . 16
2.4
Fieldbus connection
. . . . . . . . . . . . . . . . . . . . . . . . . . . . . . . . . . . . . . . . . . . . . . . . . . . . . . . . . . . . . . . . . . . . . . . . . . . . . . . . . . . . . . . . . . . . . . . . . . . . . . . 17
3
Operation
. . . . . . . . . . . . . . . . . . . . . . . . . . . . . . . . . . . . . . . . . . . . . . . . . . . . . . . . . . . . . . . . . . . . . . . . . . . . . . . . . . . . . . . . . . . . . . . . . . . . . . . . . . . . . . 17
3.1
General procedures
. . . . . . . . . . . . . . . . . . . . . . . . . . . . . . . . . . . . . . . . . . . . . . . . . . . . . . . . . . . . . . . . . . . . . . . . . . . . . . . . . . . . . . . . . . . . . . . . . . . . . . . . . . . . . . 17
3.1.1
Powering up
. . . . . . . . . . . . . . . . . . . . . . . . . . . . . . . . . . . . . . . . . . . . . . . . . . . . . . . . . . . . . . . . . . . . . . . . . . . . . . . . . . . . . . . . . . . . . . . . . . . . . . . . . . . . . . 17
3.1.2
First use
. . . . . . . . . . . . . . . . . . . . . . . . . . . . . . . . . . . . . . . . . . . . . . . . . . . . . . . . . . . . . . . . . . . . . . . . . . . . . . . . . . . . . . . . . . . . . . . . . . . . . . . . . . . . . . 17
3.1.3
After use
. . . . . . . . . . . . . . . . . . . . . . . . . . . . . . . . . . . . . . . . . . . . . . . . . . . . . . . . . . . . . . . . . . . . . . . . . . . . . . . . . . . . . . . . . . . . . . . . . . . . . . . . . . . . . . 17
3.1.4
Powering down
. . . . . . . . . . . . . . . . . . . . . . . . . . . . . . . . . . . . . . . . . . . . . . . . . . . . . . . . . . . . . . . . . . . . . . . . . . . . . . . . . . . . . . . . . . . . . . . . . . . . . . . . . . . . . . 18
3.1.5
Instrument status
. . . . . . . . . . . . . . . . . . . . . . . . . . . . . . . . . . . . . . . . . . . . . . . . . . . . . . . . . . . . . . . . . . . . . . . . . . . . . . . . . . . . . . . . . . . . . . . . . . . . . . . . . . . . . . 18
3.1.6
Shut-off valve status
. . . . . . . . . . . . . . . . . . . . . . . . . . . . . . . . . . . . . . . . . . . . . . . . . . . . . . . . . . . . . . . . . . . . . . . . . . . . . . . . . . . . . . . . . . . . . . . . . . . . . . . . . . . . . . 18
3.2
Special procedures
. . . . . . . . . . . . . . . . . . . . . . . . . . . . . . . . . . . . . . . . . . . . . . . . . . . . . . . . . . . . . . . . . . . . . . . . . . . . . . . . . . . . . . . . . . . . . . . . . . . . . . . . . . . . . . 18
3.2.1
Changing fieldbus settings (FLOW-BUS/Modbus)
. . . . . . . . . . . . . . . . . . . . . . . . . . . . . . . . . . . . . . . . . . . . . . . . . . . . . . . . . . . . . . . . . . . . . . . . . . . . . . . . . . . . . . . . . . . . . . . . . . . . . . . . . . . . . . 19
3.2.2
Changing fieldbus settings (Ethernet)
. . . . . . . . . . . . . . . . . . . . . . . . . . . . . . . . . . . . . . . . . . . . . . . . . . . . . . . . . . . . . . . . . . . . . . . . . . . . . . . . . . . . . . . . . . . . . . . . . . . . . . . . . . . . . . 19
3.2.3
Fluid selection
. . . . . . . . . . . . . . . . . . . . . . . . . . . . . . . . . . . . . . . . . . . . . . . . . . . . . . . . . . . . . . . . . . . . . . . . . . . . . . . . . . . . . . . . . . . . . . . . . . . . . . . . . . . . . . 20
3.2.4
Customizing shut-off valve behavior (FF-annS only)
. . . . . . . . . . . . . . . . . . . . . . . . . . . . . . . . . . . . . . . . . . . . . . . . . . . . . . . . . . . . . . . . . . . . . . . . . . . . . . . . . . . . . . . . . . . . . . . . . . . . . . . . . . . . . . 21
3.2.5
Switching control function
. . . . . . . . . . . . . . . . . . . . . . . . . . . . . . . . . . . . . . . . . . . . . . . . . . . . . . . . . . . . . . . . . . . . . . . . . . . . . . . . . . . . . . . . . . . . . . . . . . . . . . . . . . . . . . 22
3.2.6
Bluetooth configuration
. . . . . . . . . . . . . . . . . . . . . . . . . . . . . . . . . . . . . . . . . . . . . . . . . . . . . . . . . . . . . . . . . . . . . . . . . . . . . . . . . . . . . . . . . . . . . . . . . . . . . . . . . . . . . . 22
3.2.7
Adjusting zero point
. . . . . . . . . . . . . . . . . . . . . . . . . . . . . . . . . . . . . . . . . . . . . . . . . . . . . . . . . . . . . . . . . . . . . . . . . . . . . . . . . . . . . . . . . . . . . . . . . . . . . . . . . . . . . . 23
3.3
Maintenance
. . . . . . . . . . . . . . . . . . . . . . . . . . . . . . . . . . . . . . . . . . . . . . . . . . . . . . . . . . . . . . . . . . . . . . . . . . . . . . . . . . . . . . . . . . . . . . . . . . . . . . . . . . . . . . 23
3.3.1
Cleaning
. . . . . . . . . . . . . . . . . . . . . . . . . . . . . . . . . . . . . . . . . . . . . . . . . . . . . . . . . . . . . . . . . . . . . . . . . . . . . . . . . . . . . . . . . . . . . . . . . . . . . . . . . . . . . . 23
3.3.2
Calibration
. . . . . . . . . . . . . . . . . . . . . . . . . . . . . . . . . . . . . . . . . . . . . . . . . . . . . . . . . . . . . . . . . . . . . . . . . . . . . . . . . . . . . . . . . . . . . . . . . . . . . . . . . . . . . . 23
3.4
Troubleshooting
. . . . . . . . . . . . . . . . . . . . . . . . . . . . . . . . . . . . . . . . . . . . . . . . . . . . . . . . . . . . . . . . . . . . . . . . . . . . . . . . . . . . . . . . . . . . . . . . . . . . . . . . . . . . . . 24
3.4.1
Zooming in on NAMUR status
. . . . . . . . . . . . . . . . . . . . . . . . . . . . . . . . . . . . . . . . . . . . . . . . . . . . . . . . . . . . . . . . . . . . . . . . . . . . . . . . . . . . . . . . . . . . . . . . . . . . . . . . . . . . . . 24
3.4.2
Default valve state
. . . . . . . . . . . . . . . . . . . . . . . . . . . . . . . . . . . . . . . . . . . . . . . . . . . . . . . . . . . . . . . . . . . . . . . . . . . . . . . . . . . . . . . . . . . . . . . . . . . . . . . . . . . . . . 24
3.4.3
Common issues

## Page 6

Bronkhorst®
Instruction Manual FLEXI-FLOW™ Compact
9.17.158I
6
. . . . . . . . . . . . . . . . . . . . . . . . . . . . . . . . . . . . . . . . . . . . . . . . . . . . . . . . . . . . . . . . . . . . . . . . . . . . . . . . . . . . . . . . . . . . . . . . . . . . . . . . . . . . . . 26
3.5
Returns
. . . . . . . . . . . . . . . . . . . . . . . . . . . . . . . . . . . . . . . . . . . . . . . . . . . . . . . . . . . . . . . . . . . . . . . . . . . . . . . . . . . . . . . . . . . . . . . . . . . . . . . . . . . . . . 26
3.5.1
Removal and return instructions
. . . . . . . . . . . . . . . . . . . . . . . . . . . . . . . . . . . . . . . . . . . . . . . . . . . . . . . . . . . . . . . . . . . . . . . . . . . . . . . . . . . . . . . . . . . . . . . . . . . . . . . . . . . . . . 26
3.5.2
Disposal (end of lifetime)
. . . . . . . . . . . . . . . . . . . . . . . . . . . . . . . . . . . . . . . . . . . . . . . . . . . . . . . . . . . . . . . . . . . . . . . . . . . . . . . . . . . . . . . . . . . . . . . . . . . . . . . 27
4
Communication interface
. . . . . . . . . . . . . . . . . . . . . . . . . . . . . . . . . . . . . . . . . . . . . . . . . . . . . . . . . . . . . . . . . . . . . . . . . . . . . . . . . . . . . . . . . . . . . . . . . . . . . . . . . . . . . . 27
4.1
Configuration
. . . . . . . . . . . . . . . . . . . . . . . . . . . . . . . . . . . . . . . . . . . . . . . . . . . . . . . . . . . . . . . . . . . . . . . . . . . . . . . . . . . . . . . . . . . . . . . . . . . . . . . . . . . . . . 27
4.2
Communication protocol
. . . . . . . . . . . . . . . . . . . . . . . . . . . . . . . . . . . . . . . . . . . . . . . . . . . . . . . . . . . . . . . . . . . . . . . . . . . . . . . . . . . . . . . . . . . . . . . . . . . . . . . . . . . . . . 28
4.3
Parameters
. . . . . . . . . . . . . . . . . . . . . . . . . . . . . . . . . . . . . . . . . . . . . . . . . . . . . . . . . . . . . . . . . . . . . . . . . . . . . . . . . . . . . . . . . . . . . . . . . . . . . . . . . . . . . . 29
4.3.1
Measurement and control
. . . . . . . . . . . . . . . . . . . . . . . . . . . . . . . . . . . . . . . . . . . . . . . . . . . . . . . . . . . . . . . . . . . . . . . . . . . . . . . . . . . . . . . . . . . . . . . . . . . . . . . . . . . . . . 30
4.3.1.1
Advanced measurement and control
. . . . . . . . . . . . . . . . . . . . . . . . . . . . . . . . . . . . . . . . . . . . . . . . . . . . . . . . . . . . . . . . . . . . . . . . . . . . . . . . . . . . . . . . . . . . . . . . . . . . . . . . . . . . . . 30
4.3.2
Alarms
. . . . . . . . . . . . . . . . . . . . . . . . . . . . . . . . . . . . . . . . . . . . . . . . . . . . . . . . . . . . . . . . . . . . . . . . . . . . . . . . . . . . . . . . . . . . . . . . . . . . . . . . . . . . . . 32
4.3.3
Counter
. . . . . . . . . . . . . . . . . . . . . . . . . . . . . . . . . . . . . . . . . . . . . . . . . . . . . . . . . . . . . . . . . . . . . . . . . . . . . . . . . . . . . . . . . . . . . . . . . . . . . . . . . . . . . . 34
4.3.4
Network configuration
. . . . . . . . . . . . . . . . . . . . . . . . . . . . . . . . . . . . . . . . . . . . . . . . . . . . . . . . . . . . . . . . . . . . . . . . . . . . . . . . . . . . . . . . . . . . . . . . . . . . . . . . . . . . . . 35
4.3.4.1
Node address settings
. . . . . . . . . . . . . . . . . . . . . . . . . . . . . . . . . . . . . . . . . . . . . . . . . . . . . . . . . . . . . . . . . . . . . . . . . . . . . . . . . . . . . . . . . . . . . . . . . . . . . . . . . . . . . . 36
4.3.4.2
IP address settings
. . . . . . . . . . . . . . . . . . . . . . . . . . . . . . . . . . . . . . . . . . . . . . . . . . . . . . . . . . . . . . . . . . . . . . . . . . . . . . . . . . . . . . . . . . . . . . . . . . . . . . . . . . . . . . 36
4.3.5
Fluid set
. . . . . . . . . . . . . . . . . . . . . . . . . . . . . . . . . . . . . . . . . . . . . . . . . . . . . . . . . . . . . . . . . . . . . . . . . . . . . . . . . . . . . . . . . . . . . . . . . . . . . . . . . . . . . . 37
4.3.5.1
Advanced fluid set parameters
. . . . . . . . . . . . . . . . . . . . . . . . . . . . . . . . . . . . . . . . . . . . . . . . . . . . . . . . . . . . . . . . . . . . . . . . . . . . . . . . . . . . . . . . . . . . . . . . . . . . . . . . . . . . . . 38
4.3.5.2
Fluid mixture parameters
. . . . . . . . . . . . . . . . . . . . . . . . . . . . . . . . . . . . . . . . . . . . . . . . . . . . . . . . . . . . . . . . . . . . . . . . . . . . . . . . . . . . . . . . . . . . . . . . . . . . . . . . . . . . . . 39
4.3.6
Master/slave configuration (FLOW-BUS)
. . . . . . . . . . . . . . . . . . . . . . . . . . . . . . . . . . . . . . . . . . . . . . . . . . . . . . . . . . . . . . . . . . . . . . . . . . . . . . . . . . . . . . . . . . . . . . . . . . . . . . . . . . . . . . 40
4.3.7
Shut-off valve settings (FF-annS only)
. . . . . . . . . . . . . . . . . . . . . . . . . . . . . . . . . . . . . . . . . . . . . . . . . . . . . . . . . . . . . . . . . . . . . . . . . . . . . . . . . . . . . . . . . . . . . . . . . . . . . . . . . . . . . . 41
4.3.8
Device identification
. . . . . . . . . . . . . . . . . . . . . . . . . . . . . . . . . . . . . . . . . . . . . . . . . . . . . . . . . . . . . . . . . . . . . . . . . . . . . . . . . . . . . . . . . . . . . . . . . . . . . . . . . . . . . . 42
4.3.9
Bluetooth
. . . . . . . . . . . . . . . . . . . . . . . . . . . . . . . . . . . . . . . . . . . . . . . . . . . . . . . . . . . . . . . . . . . . . . . . . . . . . . . . . . . . . . . . . . . . . . . . . . . . . . . . . . . . . . 43
4.3.10
Operational history
. . . . . . . . . . . . . . . . . . . . . . . . . . . . . . . . . . . . . . . . . . . . . . . . . . . . . . . . . . . . . . . . . . . . . . . . . . . . . . . . . . . . . . . . . . . . . . . . . . . . . . . . . . . . . . 44
4.3.11
Diagnostics
. . . . . . . . . . . . . . . . . . . . . . . . . . . . . . . . . . . . . . . . . . . . . . . . . . . . . . . . . . . . . . . . . . . . . . . . . . . . . . . . . . . . . . . . . . . . . . . . . . . . . . . . . . . . . . 45
4.3.12
Special parameters
. . . . . . . . . . . . . . . . . . . . . . . . . . . . . . . . . . . . . . . . . . . . . . . . . . . . . . . . . . . . . . . . . . . . . . . . . . . . . . . . . . . . . . . . . . . . . . . . . . . . . . . . . . . . . . 47
4.4
Multi-parameter addressing
. . . . . . . . . . . . . . . . . . . . . . . . . . . . . . . . . . . . . . . . . . . . . . . . . . . . . . . . . . . . . . . . . . . . . . . . . . . . . . . . . . . . . . . . . . . . . . . . . . . . . . . . . . . . . . 48
4.5
Gateway (multi-channel systems)
. . . . . . . . . . . . . . . . . . . . . . . . . . . . . . . . . . . . . . . . . . . . . . . . . . . . . . . . . . . . . . . . . . . . . . . . . . . . . . . . . . . . . . . . . . . . . . . . . . . . . . . . . . . . . . 51
Parameter index

## Page 7

Bronkhorst®
Instruction Manual FLEXI-FLOW™ Compact
9.17.158I
7
1
General information
1.1
Scope of this document
This document contains information for basic installation, commissioning, operation and maintenance of the following FLEXIFLOW™ Compact models:
Model name
Model code*
Preconfigured Standard flow controller
FF-Sxxx
Preconfigured Advanced flow controller
FF-Axxx
Flow meter/controller
FF-ann
Flow controller with down ported fluid connectors
FF-annD
Flow controller with integrated shut-off valve
FF-annS
*) a=letter, n=digit, x=letter or digit
1.2
Declaration of conformity
The CE mark on the product indicates that it complies with requirements imposed by the European Union.
The UKCA mark on the product indicates that it complies with requirements imposed by the United Kingdom.
Declarations of Conformity applicable to standard Bronkhorst® products can be downloaded from
www.bronkhorst.com/downloads
1.3
Intended use
The FLEXI-FLOW has been developed to measure and/or control mass flow rates and pressures of clean, dry, non-corrosive and
non-toxic gases in a fluid system.
The product is suited for general purpose dry indoor applications, like laboratories and machine enclosures, applying media and
operating conditions within the limits as specified in the datasheet
 and in this document.
Any other use is considered not intended and improper. Improper use might cause damage to the product and/or propose
danger to users and/or bystanders and is therefore not permissible.
Responsibility for application of the product in accordance with its intended use, suitability for the intended application,
cleaning and compatibility of the used media with the applied materials lies solely with the user.
Bronkhorst High-Tech B.V. cannot be held liable for any damage and/or injury resulting from unintended, improper or unsafe
use.
11

## Page 8

Bronkhorst®
Instruction Manual FLEXI-FLOW™ Compact
9.17.158I
8
1.4
Product overview
2
0
8
4
6 5
3
1
9
7
4
5
6
7
1
2
3
FF-ann / FF-Sxxx / FF-Axxx
1.
Fluid inlet
2.
Support interface (USB-C)
3.
Address selector
4.
Power and signal connector (9-pin D-sub)
5.
Status LED
6.
Control valve (only MFC)
7.
Fluid outlet
2
0
8
4
6 5
3
1
9
7
4
5
6
7
2
3
1
FF-annD (down ported fluid connectors)
1.
Fluid inlet
2.
Support interface (USB-C)
3.
Address selector
4.
Power and signal connector (9-pin D-sub)
5.
Status LED
6.
Control valve (only MFC)
7.
Fluid outlet
4
5
7
1
8
2
3
6
IN
OUT
FF-ann / FF-annD with Ethernet interface
1.
Fluid inlet
2.
Support interface (USB-C)
3.
Ethernet interface
4.
Power and signal connector (9-pin D-sub)
5.
Status LED
6.
Address selectors
7.
Control valve (only MFC)
8.
Fluid outlet

## Page 9

Bronkhorst®
Instruction Manual FLEXI-FLOW™ Compact
9.17.158I
9
2
0
8
4
6 5
3
1
9
7
4
6
5
8
7
9
1
2
3
FF-annS (with integrated shut-off valve)
1.
Fluid inlet
2.
Support interface (USB-C)
3.
Address selector
4.
Power and signal connector (9-pin D-sub)
5.
Status LED (controller)
6.
Control valve
7.
Status LED (shut-off valve)
8.
Shut-off valve
9.
Fluid outlet
4
5
9
8
7
1
10
2
3
6
IN
OUT
FF-annS with Ethernet interface
1.
Fluid inlet
2.
Support interface (USB-C)
3.
Ethernet interface
4.
Power and signal connector (9-pin D-sub)
5.
Status LED (controller)
6.
Address selectors
7.
Status LED 9 (shut-off valve)
8.
Control valve
9.
Shut-off valve
10. Fluid outlet

## Page 10

Bronkhorst®
Instruction Manual FLEXI-FLOW™ Compact
9.17.158I
10
1.5
Product features
1.5.1
Offline/parallel configuration
The instrument is fitted with a support interface (USB-C) and an optional Bluetooth® wireless connection. Both interfaces can be
used to configure the instrument
 before process integration. After process integration, both connections can also be used to
monitor the instrument without disconnecting the operational communication connection.
Note: All information in this document regarding the Bluetooth® functionality of the FLEXI-FLOW does not apply to instruments
ordered without this functionality.
1.5.2
NAMUR instrument status
With the status indication LED
, the FLEXI-FLOW™ Compact shows its current status
, using a color range based on the
NAMUR NE 107 standard. The colors provide easily recognizable signals to the operator regarding corrective actions,
malfunctions, maintenance indications, etc.
Comprehensive diagnostic information based on the NAMUR status is available in Bronkhorst FlowSuite.
1.5.3
Multi-parameter functionality
Upon delivery, the FLEXI-FLOW™ Compact is configured as a (mass) flow controller or meter. 2 integrated pressure sensors
provide additional real-time measurement data, and allow the main instrument function to be switched between flow control
and pressure control
. Upon request, the instrument can also be supplied without this functionality. More real-time
measurement data is provided by an on-board temperature sensor.
1.5.4
On-board FLUIDAT® database
A built-in database with properties of 22 commonly used gases provides the basis for up to 8 fluid presets, which can be stored
in the instrument using Bronkhorst FlowSuite or by direct digital communication (e.g. using a custom-built (PLC) program).
The on-board FLUIDAT® conversion algorithm continuously adjusts the gas flow relative to the calibration gas, based on the
measured temperature and pressure and the properties of the selected gas (or mixture)
.
1.5.5
Multi-channel systems
The FLEXI-FLOW™ Compact can be supplied as a multi-channel system with up to 8 instruments which are linked fluidically by
means of a manifold-like construction. The instruments can be controlled individually with Modbus RTU, FLOW-BUS or an
Ethernet based communication protocol, or through a gateway
 in other fieldbus systems. The gateway and the instruments
behind it are powered through a single cable.
For information about FLEXI-FLOW™ Compact based multi-channel systems and possible applications, contact your
Bronkhorst representative.
27
8
18
21
19
48

## Page 11

Bronkhorst®
Instruction Manual FLEXI-FLOW™ Compact
9.17.158I
11
1.6
Documentation
· At some points this document refers to documentation associated with important
components or features.
· The documents listed in the following table are available on the FLEXI-FLOW product page
(www.bronkhorst.com/flexi-flow or scan the QR code).
Type
Document name
Document no.
Manuals
Instruction Manual FLEXI-FLOW™ Compact
(this document)
9.17.158
Quick Start Guide FLEXI-FLOW™ Compact
9.17.182
Quick Start Guide FLEXI-FLOW™ Compact FF-annS
9.17.186
Mounting Instruction Compression Fittings
9.17.170
Mounting instruction Compression Fittings ISO
9.17.210
Mounting Instruction Push-in Fittings
9.17.171
Mounting Instruction FF-annD
9.17.181
Technical documentation
Datasheet (technical specifications)
-
Hook-up diagram Ethernet based
9.16.313
Hook-up diagram Ethernet based (FF-annS)
9.16.314
Hook-up diagram Modbus RTU / FLOW-BUS
9.16.275
Hook-up diagram Modbus RTU / FLOW-BUS (FF-annS)
9.16.276
Hook-up diagram Modbus RTU / FLOW-BUS (Multi-channel)
9.16.296
Hook-up diagram PROFINET (Multi-channel)
9.16.297
Hook-up diagram PROFIBUS DP (Multi-channel)
9.16.298
Dimensional drawing FF-a0n
7.15.287
Dimensional drawing FF-a1n
7.15.225
Dimensional drawing FF-a2n
7.15.288
Dimensional drawing FF-annD
7.15.285
Dimensional drawing FF-annS
7.15.286

## Page 12

Bronkhorst®
Instruction Manual FLEXI-FLOW™ Compact
9.17.158I
12
The documents listed in the following table can be downloaded from www.bronkhorst.com/downloads.
Type
Document name
Document no.
Manuals
Manual EtherCAT® interface
9.17.063
Manual EtherNet/IP™ interface
9.17.132
Manual FLOW-BUS interface
9.17.024
Manual Modbus interface (RTU & TCP)
9.17.035
Manual POWERLINK interface
9.17.142
Manual PROFINET interface
9.17.095
Manual RS-232 interface*
9.17.027
Compliance
EU Declaration of Conformity FLEXI-FLOW
9.06.132
EU Declaration of Conformity RoHS
9.06.124
Manufacturer Declaration REACH
9.06.056
Manufacturer Declaration WEEE
9.06.128
Conflict Minerals Compliance Policy
9.06.065
*) Note that the FLEXI-FLOW has no RS-232 communication interface. The RS-232 manual provides useful information about the
ProPar protocol.
1.7
Safety notes
Please read this document entirely and carefully before installing and operating the product. Not following the
guidelines could result in personal injury and damage to the product and the system(s) it is incorporated in or
connected with.
· The user is considered to have a professional experience level and knowledge about installation, operational
requirements for its industry and type of application and national requirements according to relevant standards
and regulations.
· The user is responsible for taking the necessary safety measures to prevent damage and/or injury while working
with the equipment and process media (as described in the associated Material Safety Data Sheets).
· The equipment and its accessories must be used in accordance with their specifications and intended use.
· If the product is defective or otherwise does not meet your requirements, please contact your Bronkhorst
representative for assistance.
· The product may not be disassembled or modified in any way or for any purpose.
· Unauthorized modifications to the product can undo safety features, compromise system specifications and cause
failure to comply with applicable laws, regulations and directives.
· Any modification that is not authorized by the manufacturer of the product, will be considered as unintended and
improper use
.
Product related safety warnings
Before operating the product, make sure that it has been installed and configured by an authorized engineer and
that the installation is approved for use.
To ensure and maintain a safe working area, regularly inspect electrical and fluid lines and connections:
· Prior to each use, check cabling for proper connection, damage and wear. If necessary, replace cables and/or
connectors.
· Before, during and after operation, check fluid lines and connections for leaks, damage and wear. If necessary, retighten or replace fluid connectors.
During operation, fluid connections must not be loosened or disconnected under any circumstances.
When pressurizing, prevent pressure shocks by gradually bringing the fluid system to the required operating
pressure.
7

## Page 13

Bronkhorst®
Instruction Manual FLEXI-FLOW™ Compact
9.17.158I
13
Bronkhorst does the utmost to ensure that you receive a clean product. This does not, however, relieve the user of the
responsibility to ensure that the equipment and the system in which it is incorporated meet the requirements implied
by the intended use of the product. The responsibility for cleaning the equipment to meet such requirements lies
exclusively with the user.
· Depending on the properties of the process medium and the (expected) time until the next use, it is advisable to
flush the fluid system with a suitable (cleaning) fluid after use.
· If the equipment has been used to process corrosive, reactive or hazardous media (e.g. toxic or flammable),
cleaning the fluid system is imperative before it is exposed to air.
· If the equipment is not used for an extended period, the fluid system should be dry after use and after cleaning. If it
is not dry, it should be purged with a dry, inert gas for a minimum period of 30 minutes.
· Prior to powering down the product, the fluid system should be depressurized.
· When depressurizing, prevent pressure shocks by shutting off the fluid supply gradually.
Inexpertly servicing instruments can lead to serious personal injury and/or damage to the product or the system it is
used in. Servicing must therefore be performed by trained and qualified personnel. Contact your Bronkhorst
representative for information about cleaning and calibration. Bronkhorst has trained staff available.
· Before disconnecting or disassembling any fluid system related parts, always make sure the fluid system is
depressurized to atmospheric pressure.
· When depressurizing, prevent sudden pressure changes by shutting off the fluid supply gradually.

## Page 14

Bronkhorst®
Instruction Manual FLEXI-FLOW™ Compact
9.17.158I
14
2
Installation
2.1
Product specifications
Before installing the FLEXI-FLOW, check that the functional and technical properties of the product
match your requirements (the image on the right is an example; it does not necessarily reflect the
actual specifications of your instrument).
If you have a question about the product or if you find the product does not meet the specifications
as ordered, do not hesitate to contact your Bronkhorst representative (see the first pages of this
document for contact information).
2.1.1
Pressure rating
A red label signifies that the FLEXI-FLOW has undergone a pressure test and a test for
outboard leakage.
· If  the red label is missing, the device must not be used and should be returned to the
factory.
· Before installation, make sure that the pressure rating is within the limits of the normal process conditions of your
application.
2.1.2
Bluetooth certification
Connectivity
Bluetooth version
5.2
Frequency range
2402…2480 MHz
Transmitter power
max. +6 dBm
Range
max. 75 m
FCC (USA): YCP-STM32WB5M001
Note: This equipment has been tested and found to comply with the limits for a Class A digital device, pursuant to part 15 of the
FCC Rules. These limits are designed to provide reasonable protection against harmful interference when the equipment is
operated in a commercial environment. This equipment generates, uses, and can radiate radio frequency energy and, if not
installed and used in accordance with the instruction manual, may cause harmful interference to radio communications.
Operation of this equipment in a residential area is likely to cause harmful interference in which case the user will be required
to correct the interference at his own expense.
ISED (Canada): 8976A-STM32WB5M01
Notes: This device contains licence-exempt transmitter(s)/receiver(s) that comply with Innovation, Science and Economic
Development Canada’s licence-exempt RSS(s). Operation is subject to the following two conditions:
1.
This device may not cause interference.
2.
This device must accept any interference, including interference that may cause undesired operation of the device.
JRF (Japan): 005-102490
NCC (Taiwan): CCAN20LP0740T3
2.2
Mounting
For optimal performance, observe the following guidelines:
· Avoid installation in close proximity of mechanical vibration and/or heat sources.
· Use the equipment in an environment with a stable ambient pressure and temperature.
· Attach the instrument body to a rigid and stable surface or construction.

## Page 15

Bronkhorst®
Instruction Manual FLEXI-FLOW™ Compact
9.17.158I
15
Instrument with regular fluid couplings
Use the threaded mounting holes in the bottom of the instrument base. Consult the dimensional
drawing
 for the exact size and locations.
Instrument with down ported fluid couplings
· Consult the dimensional drawing
 for details about the instrument footprint and mounting
pattern.
· Follow the mounting instructions for FF-annD instruments
.
2.2.1
Piping requirements
· For reliable performance, make sure the fluid stream is uncontaminated. If necessary, use an inlet filter to ensure a
particle free media stream. Select a filter with a maximum pore size of 20 µm and a surface area that minimizes the
pressure drop.
· If back flow could occur, the use of a check valve is also recommended.
Use piping or tubing that is suitable for the operating conditions of the application (media, maximum temperature,
maximum operating pressure).
2.2.2
Fluid connection
· Connect the FLEXI-FLOW to the fluid system in accordance with the indications in the product overview
.
· Consult the dimensional drawing
 for the according instrument model for details about the fitting cavities.
· Make sure connector sizes match; do not mix metric (mm) and imperial (inch) sizes.
· Make sure all connectors and tubing are free from dirt and debris.
· Follow the mounting instructions
 for the according fluid connectors.
Do not apply fluid pressure until all required fluid connections and electrical connections have been made.
Check the fluid system for leak tightness after any modification and before applying full operating pressure, especially
when using hazardous media (e.g. toxic or flammable).
2.2.3
Preventing pressure shocks
The product can handle pressure shocks in the system well, but is not insensitive to pressure fluctuations. For optimal
control stability, observe the following guidelines:
· Provide a stable (pressure controlled) upstream pressure; put sufficient buffer volume between a pressure
regulator and the instrument. As a rule of thumb, install pressure regulators at a distance of at least 25 times the
pipe diameter from the inlet or outlet of the instrument.
· When using multiple instruments and/or control valves, prevent interference by putting piping with sufficient
buffer volume between components.
11
11
11
8
11
11

## Page 16

Bronkhorst®
Instruction Manual FLEXI-FLOW™ Compact
9.17.158I
16
2.3
Electrical connection
· Electrical connections should be made according to the applicable hook-up diagram
, using the supplied cables (insofar
as included) or compatible, with respect to required supply current, voltage loss, cable  length, cable and gland diameters
and operating conditions.
· When using self-assembled cables, follow the guidelines provided by the connectors' manufacturer.
· For use in a fieldbus system, follow the instructions of the cable supplier for the according fieldbus system.
· Make sure that the power supply matches the power rating of the instrument (see technical specifications
) and that
double or reinforced insulation is used for the power supply.
· If a surge protection device is used, make sure its specifications match the power consumption of the application.
To prevent damage as a result of reversed polarity, the use of a 2A fuse in the direct +Us line is recommended.
Always turn off electrical power before connecting or disconnecting equipment electrically.
In order to be able to comply with all applicable guidelines and regulations, it is imperative that electrical connections
be made by or under supervision of a qualified electrician.
· The equipment described in this document contains electronic components that are susceptible to electrostatic
discharge.
· When working on the electrical installation, take appropriate measures to prevent damage as a result of
electrostatic discharge.
The CE mark on the equipment indicates that it complies with requirements imposed by the European Union.
The UKCA mark indicates compliance with requirements imposed by the United Kingdom.
In both cases, the requirements include electromagnetic compatibility (EMC).
EMC can only be guaranteed by applying appropriate cables and connectors or gland assemblies:
· Cable wire diameters must be sufficient to carry the supply current and minimize voltage loss.
· When connecting the product to other devices, ensure that the integrity of the shielding remains uncompromised;
use shielded cables and connectors where possible and/or required.
· Preferably use the supplied cables (if applicable) to make electrical (signal) connections to and between the
supplied components. These cables are shielded, have the required wire diameter, and loose ends (if applicable) are
marked to facilitate correct connection.
If not all requirements for proper shielding can be met (for example, because a component is not equipped with
shielded connectors), take the following measures to ensure the best possible shielding:
· Keep cable lengths at a minimum.
· Route cables as closely as possible alongside metal structures or components.
· Ensure all electrical components are grounded to earth.
When in doubt about the shielding of your cabling and/or electrical connections, contact your Bronkhorst
representative.
2.4
Fieldbus connection
Always check the total power consumption of your instruments before connecting them to a fieldbus system. Do not
exceed the maximum power of the power supply unit.
· For fieldbus related wiring details, consult the according hook-up diagram
.
· For information about setting up a fieldbus network with Bronkhorst® instruments, consult the according fieldbus
manual
.
· If you need assistance with setting up a fieldbus network, contactyour Bronkhorst representative for information.
11
11
11
11

## Page 17

Bronkhorst®
Instruction Manual FLEXI-FLOW™ Compact
9.17.158I
17
3
Operation
3.1
General procedures
Before operating the product, make sure that it has been installed and configured by an authorized engineer and
that the installation is approved for use.
To ensure and maintain a safe working area, regularly inspect electrical and fluid lines and connections:
· Prior to each use, check cabling for proper connection, damage and wear. If necessary, replace cables and/or
connectors.
· Before, during and after operation, check fluid lines and connections for leaks, damage and wear. If necessary, retighten or replace fluid connectors.
During operation, fluid connections must not be loosened or disconnected under any circumstances.
Gas condensation in the instrument can seriously affect its performance and reliability.
· If possible, ensure that the ambient temperature is stable and at equal to or slightly higher than the process gas
temperature.
· Always use a clean and dry process gas (preferably with a purity of at least 99.5 %).
3.1.1
Powering up
To maintain control of the fluid system and ensure a safe situation, it is recommended to turn on power before
applying fluid pressure and to switch off power only after the fluid system is depressurized.
When pressurizing, prevent pressure shocks by gradually bringing the fluid system to the required operating
pressure.
· When powering up, the instrument needs a couple of seconds to start up the electronics and perform a self-test.
· During initialization, the status LED cycles through all NAMUR status colors
.
· After successful initialization, the status LED lights up green to indicate that the instrument is ready to be used.
After powering up, the control valve will act according to the last known setpoint. When setpoint is 0, this means the
valve closes (normally open) or stays closed (normally closed). The valve stays closed until the instrument receives a
new valid setpoint from the active setpoint source.
3.1.2
First use
Bronkhorst does the utmost to ensure that you receive a clean product. This does not, however, relieve the user of the
responsibility to ensure that the equipment and the system in which it is incorporated meet the requirements implied
by the intended use of the product. The responsibility for cleaning the equipment to meet such requirements lies
exclusively with the user.
3.1.3
After use
· Depending on the properties of the process medium and the (expected) time until the next use, it is advisable to
flush the fluid system with a suitable (cleaning) fluid after use.
· If the equipment has been used to process corrosive, reactive or hazardous media (e.g. toxic or flammable),
cleaning the fluid system is imperative before it is exposed to air.
· If the equipment is not used for an extended period, the fluid system should be dry after use and after cleaning. If it
is not dry, it should be purged with a dry, inert gas for a minimum period of 30 minutes.
3.1.4
Powering down
· Prior to powering down the product, the fluid system should be depressurized.
· When depressurizing, prevent pressure shocks by shutting off the fluid supply gradually.
10

## Page 18

Bronkhorst®
Instruction Manual FLEXI-FLOW™ Compact
9.17.158I
18
3.1.5
Instrument status
The status LED
 uses different colors to reflect the current status of the instrument:
Green
Normal operation
Red
Failure
Yellow
Out of specification
Blue
Maintenance required
Orange
Check function
· The colors are based on the NAMUR NE 107 standard and are a simplified representation of the instrument's diagnostic
data
.
· After powering up or restarting the instrument, the status LED cycles through all status colors once.
· After the startup cycle, the status LED assumes the color associated with the current instrument status.
Bluetooth
· When Bluetooth is active, the status LED flashes blue once every 3 seconds.
· If the instrument has a Bluetooth connection, the status LED flashes blue twice every 3 seconds.
· Bluetooth communication is not reflected by the status LED.
· Bluetooth indications are not related to the blue NAMUR indication.
Zeroing
· During zero point adjustment
, the status LED blinks blue (1 second on, 1 second off).
· The zeroing indication is not related to the blue NAMUR indication.
3.1.6
Shut-off valve status
On FLEXI-FLOW models with an integrated shut-off valve (FF-annS), the status LED on the shut-off valve
 indicates its state:
Status LED
Valve state
Valve position
Normally closed
(N.C.)
Normally open
(N.O.)
On
actuated
open
closed
Off
inactive
closed
open
3.2
Special procedures
3.2.1
Changing fieldbus settings (FLOW-BUS/Modbus)
· Upon delivery, the power and signal connector
 is configured for FLOW-BUS or Modbus RTU communication interface  (see
hook-up diagram
), unless specified otherwise at ordering time.
· If necessary, use Bronkhorst FlowSuite to select the required communication interface and configure associated parameters
(fieldbus address, baud rate, parity).
· Connect the instrument with Bronkhorst FlowSuite through the support interface or the Bluetooth wireless connection.
Communication will be cut off if the selected communication protocol is changed when connected through the power and
signal connector.
· If, for some reason, Bronkhorst FlowSuite is not available, see section Network configuration
.
· A USB connection on the support interface provides sufficient power for instrument configuration and monitoring
only.
· Configuration using a Bluetooth wireless connection requires powering the instrument through the power
connector or support interface.
8
24
22
8
8
11
34

## Page 19

Bronkhorst®
Instruction Manual FLEXI-FLOW™ Compact
9.17.158I
19
Manual address selection
Assuming the default baud rate and parity match the fieldbus configuration, the fieldbus address can be quickly set using the
manual address selector
:
· With value 0, the instrument uses the digital address setting
· Values from 1 to 9 override the digital setting
3.2.2
Changing fieldbus settings (Ethernet)
· Upon delivery, the Ethernet sockets are configured for PROFINET communication, unless specified otherwise at ordering
time.
· In a PROFINET network, an IP address is assigned to the instrument by the Ethernet master.
· If necessary, use Bronkhorst FlowSuite to select the required communication interface and configure address assignment.
· Preferably connect the instrument with Bronkhorst FlowSuite through the support interface or the Bluetooth wireless
connection.
· If, for some reason, Bronkhorst FlowSuite is not available, see section Network configuration
.
· A USB connection on the support interface provides sufficient power for instrument configuration and monitoring
only.
· Configuration using a Bluetooth wireless connection requires powering the instrument through the power
connector or support interface.
Manual address selection
For Ethernet based protocols other than PROFINET, the 3 manual address selectors can be used to assign an address to the
instrument (IP/Node ID/Station alias; again, only if Bronkhorst FlowSuite is not available).
For information about setting the instrument address using the address selectors, refer to the manual for the
according communication protocol
.
MAC address
Because the IP address is set on the device (either dynamic or fixed), it is not necessarily always the same. To be able to track a
device in a network with a fixed reference, Ethernet devices also have a MAC address, which cannot be changed and is globally
unique. The MAC address is stated on a label affixed to the FLEXI-FLOW.
3.2.3
Fluid selection
Fluid sets or mixtures can be stored using Bronkhorst FlowSuite or by direct digital communication (e.g. using a custom-built
(PLC) program). To define a fluid set or mixture, only the formula of the required gas needs to be entered in the appropriate
parameter. The associated conversion parameters are filled in automatically.
Whether carried out in Bronkhorst FlowSuite or with direct digital communication, fluid and mixture definition are virtually
identical:
To define a fluid set:
1.
Select the required Fluid Set Index.
2.
Enter the formula of the required gas into parameter Fluid Name (case-sensitive).
To define a mix component:
1.
Select the required Fluid Set Index.
2.
Select the required Mix Component Index.
3.
Enter the formula of the required gas into parameter Mix Component Fluid Name (case-sensitive).
8
34
11

## Page 20

Bronkhorst®
Instruction Manual FLEXI-FLOW™ Compact
9.17.158I
20
The following gases can be selected:
Name
Formula
Acetylene
C2H2
Air
Air
Allene
C3H4 #1
Argon
Ar
Carbon dioxide
CO2
Carbon monoxide
CO
Cyclopropane
C3H6 #1
Deuterium
D2 #1
Ethane
C2H6
Ethylene
C2H4
Helium
He
Hydrogen
H2
Krypton
Kr
Methane
CH4
Neon
Ne
Nitrogen
N2
Nitrous oxide
N2O
Oxygen
O2
Perfluoropropane
C3F8
Propane
C3H8
Propylene
C3H6 #2
Propyne
C3H4 #2
· Note that the FLUIDAT® algorithm is case-sensitive regarding fluid names.
· If you need definitions for other gases, contact your Bronkhorst representative.
· Also see parameter section Fluid set
 for a complete reference of all digital fluid set parameters.
3.2.4
Customizing shut-off valve behavior (FF-annS only)
This section only applies to FLEXI-FLOW models with an integrated shut-off valve (FF-annS).
Upon delivery, actuation of the integrated shut-off valve is linked to the instrument setpoint: the valve is closed as long as
setpoint = 0 and open when setpoint > 0.
Using Bronkhorst FlowSuite, the default behavior can be reprogrammed to operate the valve manually.
After setting the valve behavior to manual control, use digital parameter IO Switch Status to operate the shut-off valve:
0 = deactivate
1 = activate, observe default/safe state
257 = activate, ignore default/safe state
Notes:
· Make sure the operating mode matches the shut-off valve function (N.C. or N.O.), otherwise the the shut-off valve
will close when the control valve is open and vice versa.
· The shut-off valve responds to IO Switch Status only if the operating mode is set to Manual.
· See Shut-off valve settings (FF-annS only)
 for information about underlying parameter and their meaning.
36
24
40

## Page 21

Bronkhorst®
Instruction Manual FLEXI-FLOW™ Compact
9.17.158I
21
3.2.5
Switching control function
· Bronkhorst FlowSuite automatically adds additional communication channels to the array as regular instruments.
· Although each communication channel represents an individual instrument, all three communication channels of
the FLEXI-FLOW have the same node address in the fieldbus network.
Control functions
The multi-parameter functionality
 enables simultaneous measurement of flow, upstream pressure and downstream
pressure, using 3 different communication channels. The selected control function determines whether the instrument uses 1 or
2 communication channels/sensors for measurement and control.
Single channel control
Using the single channel control functionality, only a single sensor is used:
Control
Function
Communication
channel
Instrument function
0
F
Flow control
1
P1
Upstream pressure control
2
P2
Downstream pressure
control
Dual channel control
Using the dual channel control functionality, a combination of the flow sensor and 1 of the pressure sensors is used, where either
the flow is controlled and the pressure is limited, or vice-versa:
Control
Function
Communication
channel
Instrument function
3
P1 + F
Upstream pressure control,
with flow limit
4
P2 + F
Downstream pressure
control, with flow limit
5
F + P1
Flow control, with upstream
pressure limit
6
F + P2
Flow control, with
downstream pressure limit
10

## Page 22

Bronkhorst®
Instruction Manual FLEXI-FLOW™ Compact
9.17.158I
22
Switching the control function
· Use parameter Control Function
 to set the instrument function.
· Give a setpoint to the controlled value.
· If dual channel control is selected: give a limit to the limited value, using the setpoint parameter of that communication
channel.
· See section Multi-parameter addressing
 for available parameters.
3.2.6
Bluetooth configuration
· The FLEXI-FLOW™ Compact is delivered with Bluetooth disabled.
· Bluetooth can be enabled using Bronkhorst FlowSuite.
· When pairing, the instrument can be recognized by its serial number.
· The first time the instrument is paired with Bronkhorst FlowSuite, a six-digit passkey must be created.
· Subsequently, the instrument can only be paired by entering the passkey that is stored in the instrument.
· After pairing the instrument, Bluetooth can also be enabled or disabled by using digital communication. See
parameter section Bluetooth
 for the according parameters.
· Configuration using a Bluetooth wireless connection requires powering the instrument through the power
connector or support interface.
3.2.7
Adjusting zero point
Zero-stability
The zero point of a Bronkhorst® flow meter/controller (the measurement signal that indicates the absence of a flow) is factory
adjusted at approximately 20 °C and atmospheric pressure (ambient conditions), with the instrument positioned upright. Under
normal circumstances (i.e. at stable process conditions), the zero point will remain stable. However, over time several factors
can induce a slight deviation of the measured value from the zero point, causing the instrument to detect a flow when in reality
there is none. Readjusting the zero point eliminates this deviation.
· After installation or relocation, always check the zero point.
· If the instrument detects a (steady) flow while all valves are closed and the fluid system is leak tight, adjusting the
zero point is recommended.
Prerequisites
Zeroing an instrument requires that:
· the ambient conditions (temperature, pressure) match those of the operating environment of the instrument.
· the instrument is filled homogeneously and pressurized with the operational media, according to the typical process
conditions.
· the instrument has been warmed up sufficiently.
· there is absolutely no flow through the instrument; preferably, this is achieved by closing a valve immediately after the outlet
of the instrument (control valve, shut-off valve).
Blocking the flow through the instrument is essential; zeroing an instrument while there is still a flow will lead to
measurement errors.
Procedure
Bronkhorst FlowSuite provides a quick and easy way to adjust the zero point of an instrument; the Autozero function
automatically performs the procedure described here.
To adjust the zero point using digital communication, set parameter values in the following sequence (see section
Parameters
 for more information about instrument parameters or click on a parameter name to jump directly to its full
description):
Sequence #
Parameter
Value
Action
1
Setpoint
 or fSetpoint
0
stop flow
2
Init Reset
64
unlock secured parameters
3
Control Mode
9
enable calibration mode
4
Calibration Mode
0
reset calibration mode
5
Calibration Mode
9
start zeroing
29
47
42
28
29
30
45
46
47
47

## Page 23

Bronkhorst®
Instruction Manual FLEXI-FLOW™ Compact
9.17.158I
23
The status LED
 starts blinking blue (1 second on, 1 second off), indicating that the procedure is in progress. On completion,
the status LED assumes the color of the current instrument status
.
If the procedure is successful, parameter Calibration Mode changes to 0 (idle). If the procedure fails, Calibration Mode changes to
255.
After zeroing, parameter Control Mode returns to its initial value. The output signal should be 0 % (parameter Measure = 0).
After performing the procedure, remember to set parameter Init Reset to value 82 to lock secured parameters.
3.3
Maintenance
Inexpertly servicing instruments can lead to serious personal injury and/or damage to the product or the system it is
used in. Servicing must therefore be performed by trained and qualified personnel. Contact your Bronkhorst
representative for information about cleaning and calibration. Bronkhorst has trained staff available.
The FLEXI-FLOW needs no regular maintenance if operated properly, with clean, non-corrosive media, compatible with the
wetted materials, avoiding pressure and thermal shocks and vibrations.
· Before disconnecting or disassembling any fluid system related parts, always make sure the fluid system is
depressurized to atmospheric pressure.
· When depressurizing, prevent sudden pressure changes by shutting off the fluid supply gradually.
3.3.1
Cleaning
Fluid path
· The instrument's fluid path (the wetted parts) may be purged with a clean, dry and inert gas.
· In case of severe contamination, cleaning the wetted parts may be necessary. This requires the instrument to be returned to
the factory.
Exterior parts
Exterior parts can be cleaned with a soft, lint free cloth, preferably dry, or, if necessary, moistened with a mild water soluble
cleaning agent.
· Moisten the cloth only slightly, to prevent liquid penetrating the interior and causing damage to the electrical
parts.
· Only use a water soluble cleaning agent, never an oil based liquid like paint thinner or white spirit, as these might
damage parts made of synthetic materials.
3.3.2
Calibration
The FLEXI-FLOW has been factory calibrated. Periodical inspection, recalibration or verification of the accuracy may be subject
to individual requirements of the user. Whenever necessary, contact your Bronkhorst representative for information and/or
making arrangements for recalibration.
Bronkhorst certifies that the instrument meets the rated accuracy. Calibration has been performed using measurement
standards traceable to the Dutch Metrology Institute (VSL).
3.4
Troubleshooting
General problems
· Electronic problems can be traced by restarting the product and/or the master application.
· If the equipment starts up normally, the measurement and control behavior can be checked by applying fluid pressure.
· To track down problems in the fluid system, depressurize the fluid system and disconnect the suspected unit from the
process line. Dirt or clogging might be quickly detected by visual inspection of disassembled fluid connections.
If you suspect leakage, do not disassemble the device for inspection, but contact your Bronkhorst representative for
service or repairs.
8
10

## Page 24

Bronkhorst®
Instruction Manual FLEXI-FLOW™ Compact
9.17.158I
24
3.4.1
Zooming in on NAMUR status
Errors and warnings
· Detailed error and warning information can be found by connecting the instrument to a Windows computer
running Bronkhorst FlowSuite. Bronkhorst FlowSuite's diagnostic function makes comprehensive diagnostic
information accessible based on the NAMUR status
.
· The built-in diagnostic instrument parameters
 which Bronkhorst FlowSuite uses for this purpose are also
available through the digital communication interface.
3.4.2
Default valve state
When a controlling instrument is not powered or cannot communicate with the fieldbus network (if applicable), all electrical
valves operated by the instrument (whether integrated or external) automatically assume their default state. The default state is
closed for 'normally closed' valves (n/c) and fully open for 'normally open' valves (n/o).
Check the serial number label or the technical specifications
 to see which valve function is used on your instrument (if
applicable).
3.4.3
Common issues
Symptom
Possible cause
Corrective action
No communication
No power supply
· Check power supply
· Check cable connection
· Check cable hook-up
Invalid address
Change node address or IP address
· see Changing fieldbus settings (FLOWBUS/Modbus)
· or Changing fieldbus settings (Ethernet)
Invalid baud rate
Make sure instrument baud rate matches
master/application baud rate
Other
Reset instrument and/or restart master. If
problem persists, contact your Bronkhorst
representative
No output signal
No power supply
· Check power supply
· Check cable connection
· Check cable hook-up
Invalid control mode (instrument
accepts no setpoint)
Check control mode (see Special parameters
)
Valve(s) in default state (normally
closed)
Check if connected valves are in default state;
solve cause if necessary (see Default valve
state
)
Upstream pressure or differential
pressure too low
Increase upstream pressure
Piping, filters and/or control valve
clogged or blocked
Clean fluid system (flush with clean, dry air)
Sensor failure
Contact your Bronkhorst representative
18
44
11
18
19
45
24

## Page 25

Bronkhorst®
Instruction Manual FLEXI-FLOW™ Compact
9.17.158I
25
Symptom
Possible cause
Corrective action
Control behavior unstable
Measurement disturbed by
vibrations
· If possible, avoid installation in close
proximity of mechanical vibration
· Reduce sensitivity to vibrations by using a
mass block, shock absorbers, and flexible
tubing
Upstream pressure unstable
Install pressure regulator or increase buffer
volume between controlling instruments
Upstream and/or downstream
pressure too high or too low
Adjust pressure and/or set instrument pressure
in accordance with actual process pressure
Wrong process gas selected
Select correct process gas
Wrong controller settings
Adjust settings (e.g. with Bronkhorst FlowSuite)
Control valve damaged
Contact your Bronkhorst representative
No flow (sending a setpoint has no
effect)
No fluid supply
Check upstream components for obstruction,
e.g.:
· fluid lines
· valves
· filters
Wrong control mode selected
· Check parameter Control mode
· Make sure instrument accepts setpoint from
actual setpoint source (bus)
Valve(s) in default state (normally
closed)
Check if valves are in default state; solve cause if
necessary (see Default valve state
)
Upstream pressure or differential
pressure out of bounds
Set upstream pressure to a value within
specifications
Flow rate never reaches setpoint
· Fluid system clogged or blocked
· Sensor obstructed or
contaminated
Flush the fluid system:
· Liquid lines with a non-aggressive cleaning
liquid (e.g. ethanol or isopropyl alcohol).
· Gas lines with clean, dry air.
Upstream pressure too low
Increase upstream pressure (to a value within
specifications).
Downstream pressure too high
Decrease downstream pressure (to a value within
specifications).
Differential pressure too low
Make sure differential pressure is within
specifications.
Process outlet blocked
Check process outlet and downstream piping.
Process gas condensation
Decrease upstream pressure or increase gas
temperature.
Supplied fluid type does not match
selected fluid type
Supply equipment with other fluid or change
fluid type in instrument configuration.
Pressure signal gradually decreasing
without setpoint change
Process gas condensation
Decrease upstream pressure or increase gas
temperature.
Measured value or output signal
indicates flow, while there should
be none
Fluid system leakage
· Check fluid system for leakage
· Follow mounting instructions when installing
third party components (e.g. adapters, tubing,
valves)
Zero point adjustment performed
incorrectly
Readjust zero point, following instructions in
Adjusting zero point
46
24
22

## Page 26

Bronkhorst®
Instruction Manual FLEXI-FLOW™ Compact
9.17.158I
26
Symptom
Possible cause
Corrective action
Continuous maximum measured
value or output signal
Upstream pressure too high
Check upstream pressure.
Control valve fully open
· Check parameter Control Mode
.
· In case of normally open valve: check if valve is
in default state; resolve cause if necessary (see
Default valve state
).
Sensor failure
Contact your Bronkhorst representative.
Fluid system leakage
Bad connection between parts (e.g.
ferrules, nuts, tubing, piping, valves)
Follow mounting instructions issued for third
party components (e.g. adapters, tubing, valves).
3.5
Returns
3.5.1
Removal and return instructions
In case the product needs to be returned (e.g. for calibration, repair), please refer to our website for information on the online
product return process (RMA).
· Visit the Bronkhorst website.
· Go to the Service & Support section.
· Follow the on-screen instructions to return the product.
3.5.2
Disposal (end of lifetime)
If you are a customer within the European Union and wish to dispose of Bronkhorst® equipment bearing the
symbol of a crossed out waste disposal bin, you can return it in accordance with the removal and return
instructions
. Bronkhorst will then take care of proper dismantling, recycling and/or reuse (wherever possible).
In the covering letter, mention that you are returning the product for disposal.
In countries outside the EU, disposal of electrical and electronic equipment (EEE) may be subject to local or
national directives and/or legislation. If applicable, consult local or national authorities to learn how to handle EEE
properly in your area.
46
24
26

## Page 27

Bronkhorst®
Instruction Manual FLEXI-FLOW™ Compact
9.17.158I
27
4
Communication interface
4.1
Configuration
Software
Configuration of the FLEXI-FLOW is best done with Bronkhorst FlowSuite, which is developed specifically for easy
configuration and monitoring of Bronkhorst® instruments. It can communicate with the FLEXI-FLOW through the support
interface
 or a Bluetooth wireless connection, without the need to break the operational communication connection.
Bronkhorst FlowSuite can be downloaded from the Bronkhorst website: www.bronkhorst.com/downloads
Support interface
· A regular USB connection provides sufficient power to allow instrument configuration outside of its operating environment.
· During operation, the USB connection can be used to change the configuration or monitor the instrument, while powered
through the main power connector.
Bluetooth
· The FLEXI-FLOW™ Compact is delivered with Bluetooth disabled; it can be enabled using Bronkhorst FlowSuite
.
· A Bluetooth wireless connection requires the instrument to be powered through the power connector or the support
interface.
· The Bluetooth wireless connection is only suitable for configuration and monitoring, but it can be used during operation.
4.2
Communication protocol
For information about the use of Bronkhorst® instruments with a specific communication protocol, consult the
according interface manual
.
FLOW-BUS
Bronkhorst FlowSuite provides a graphical interface to the ProPar
 protocol (used by FLOW-BUS), for easy configuration and
monitoring of Bronkhorst® instruments.
Modbus
In a Modbus system instruments can be monitored and operated using third party software as a master device, such as LabVIEW,
ModScan, or a Modbus PLC.
Ethernet based protocols
FLEXI-FLOW instruments with an Ethernet based communication interface support the following protocols:
· EtherCAT®
· EtherNet/IP™
· Modbus TCP
· POWERLINK
· PROFINET (default)
In an Ethernet based communication system instruments can be monitored and operated using third party software as a master
device, such as TIA Portal (by Siemens).
For most Ethernet based protocols, the master software platform needs a device description file for the according
communication protocol. The device description file contains all necessary information to operate the device in the according
system, including communication and network configuration, and all available operating parameters with their data types.
Device description files for Bronkhorst® instruments can be downloaded from the product pages on the Bronkhorst
website (search for 'fieldbus files').
8
22
11
28

## Page 28

Bronkhorst®
Instruction Manual FLEXI-FLOW™ Compact
9.17.158I
28
4.3
Parameters
A summary of all digital parameters in this section can be found in the back of this manual.
This section describes the most commonly used parameters for digital operation of the FLEXI-FLOW. Descriptions are grouped
by category in tables:
Type
Access
Range
FlowDDE
ProPar
Modbus
[type]
RW B
[x]…[y]
[DDE par]
[Pro]/[Par]
[address]/[register]
In this manual, parameter names are printed in italics (reverted to normal where embedded in italics, like in this tip).
Type
Unsigned char
1 byte unsigned integer (0…255)
Unsigned int
2 byte unsigned integer, MSB first (0…65535)
Unsigned long
4 byte unsigned integer, MSB first (0…4294967295)
Float
4 byte floating point, IEEE 32-bit single precision, MSB first
Unsigned char [x] x byte text string
String
text string of unspecified length
Access
R
Parameter value can be read
W
Parameter value can be written
B
Parameter is secured and can only be written if parameter Init Reset is set to 'unlocked' first
Range
Some parameters only support values within a certain range:
[x]
Minimum value
[y]
Maximum value
FlowDDE
Parameter number within FlowDDE
FLOW-BUS
FLOW-BUS uses the ProPar protocol, where parameters are identified by a unique combination of a process number and a
parameter number.
· For more information about setting up a FLOW-BUS network with Bronkhorst® instruments, consult the FLOW-BUS
manual (see Documentation
).
· For more information about the ProPar protocol, consult the RS-232 manual (see Documentation
).
Modbus
In the Modbus protocol, parameters are accessed by specifying their unique decimal register number or corresponding PDU
address (Protocol Data Unit). The PDU address is the hexadecimal translation of the register number, minus 1, e.g. register
number 1 corresponds to PDU address 0x0000, register number 11 corresponds to PDU address 0x000A.
Modbus address blocks are two bytes long. Larger data types use up to 8 subsequent address blocks, resulting in a maximum
variable length of 16 bytes. Values longer than the maximum length are truncated.
For more detailed information about setting up a Modbus network with Bronkhorst® instruments, consult the
Modbus manual (see Documentation
).
Other interface protocols
Parameter descriptions in this document are based on their availability with FLOW-BUS, Modbus or RS-232 (ProPar)
communication. Due to limitations in, for example, memory capacity or communication properties, definition files for other
communication protocols usually do not make all parameters available.
Not all parameters described in this document are necessarily available for all digital communication protocols. For
information about parameter access and availability for Bronkhorst® instruments in a network with a specific
communication protocol, consult the manual for the according protocol
.
11
11
11
11

## Page 29

Bronkhorst®
Instruction Manual FLEXI-FLOW™ Compact
9.17.158I
29
4.3.1
Measurement and control
Fmeasure
Type
Access
Range
FlowDDE
ProPar
Modbus
Float
R
-3.4E+38…
3.4E+38
205
33/0
0xA100…0xA101/ 41217…41218
This parameter represents the value of parameter Measure, expressed in the selected Capacity Unit. Its value is calculated from
the dimensionless value of Measure, using the fluid set parameters Capacity 100% and Capacity Unit.
Fsetpoint
Type
Access
Range
FlowDDE
ProPar
Modbus
Float
RW
0…3.4E+38
206
33/3
0xA118…0xA119/ 41241…41242
This parameter represents the value of parameter Setpoint, expressed in the selected Capacity Unit. Conversion between
Fsetpoint and the dimensionless value of Setpoint uses fluid set parameters Capacity 100% and Capacity Unit.
Control Function
Type
Access
Range
FlowDDE
ProPar
Modbus
Unsigned char
RW
0…6
432
115/10
0x0E6A/3691
· This parameter determines whether the instrument works as a flow controller or a pressure controller.
· Use the setpoint on the associated communication channel to control the flow or pressure (see section Multi-parameter
addressing
).
· The selected function is effective immediately.
· The instrument remembers the selected value on restart (persistent setting).
Available functions:
Value
Description
0
Flow
1
Upstream pressure
2
Downstream pressure
3
Upstream pressure with flow limit
4
Downstream pressure with flow limit
5
Flow with upstream pressure limit
6
Flow with downstream pressure limit
Measure
Type
Access
Range
FlowDDE
ProPar
Modbus
Unsigned int
R
0…41942
8
1/0
0x0020/33
This parameter returns a dimensionless representation of the measured flow rate or pressure. Value 32000 corresponds to 100
%, the maximum value corresponds to 131.07 %.
Setpoint
Type
Access
Range
FlowDDE
ProPar
Modbus
Unsigned int
RW
0…32000
9
1/1
0x0021/34
The value of this parameter is a dimensionless representation of the required flow rate or pressure. Value 32000 corresponds to
100 %.
47

## Page 30

Bronkhorst®
Instruction Manual FLEXI-FLOW™ Compact
9.17.158I
30
Temperature
Type
Access
Range
FlowDDE
ProPar
Modbus
Float
R
-250…500
142
33/7
0xA138…0xA139/41273…41274
This parameter returns the internal temperature in the instrument housing in °C, which is an approximation of the actual media
temperature.
4.3.1.1
Advanced measurement and control
Setpoint Slope
Type
Access
Range
FlowDDE
ProPar
Modbus
Unsigned int
RW
0…30000
10
1/2
0x0022/35
The value of this parameter represents the time it would take to adjust the setpoint if it were changed from 0 to 100%. This
feature can be used to smooth 'nervous' controller behavior, e.g. to reduce setpoint overshoot or undershoot.
The supported range corresponds to 0…3000 seconds. Default value = 0.
Example:
If Setpoint Slope = 100 it will take 10 seconds to adjust the setpoint if it is changed from 0 to 100%. A setpoint change of 20% will
take (20%/100%)*10 seconds = 2 seconds.
Valve Output
Type
Access
Range
FlowDDE
ProPar
Modbus
Unsigned long
RW
0…
16777215
55
114/1
0xF208…0xF209/61961…61962
This parameter represents the controller output signal for control valve operation.
Controller Speed
Type
Access
Range
FlowDDE
ProPar
Modbus
Float
RW B
 0…
3.40282E+3
8
254
114/30
0xF2F0…0xF2F1/62193…62194
This parameter sets the overall controller speed factor for the selected fluid set. Controller Speed is set ex factory between value
'0.5' (slow) and '2' (fast). The default value is '1'. Slower or faster settings are possible between values 0.2 and 5 at the customer's
responsibility.
4.3.2
Alarms
Alarm settings are most easily accessible using Bronkhorst FlowSuite, FlowPlot or FlowView or a Bronkhorst® readout
and control unit.
The built-in alarm functionality can be used to handle different alarm types:
· system errors and warnings
· min/max alarms
· response alarms
· batch alarms
· master/slave alarms
The alarm type can be set with parameter Alarm Mode. When an alarm is activated, the type can be read out using parameter
Alarm Info. An automatic setpoint change can be set using the parameters Alarm Setpoint Mode and Alarm New Setpoint. It is also
possible to set an alarm delay, to prevent overreaction to small disturbances, using parameter Alarm Delay Time. The methods
by which an alarm can be reset are controlled by Reset Alarm Enable.

## Page 31

Bronkhorst®
Instruction Manual FLEXI-FLOW™ Compact
9.17.158I
31
Alarm Mode
Type
Access
Range
FlowDDE
ProPar
Modbus
Unsigned char
RW
0…3
118
97/3
0x0C23/3108
Available modes:
Value
Description
0
Alarm off
1
Alarm on absolute limits
2
Alarm on limits related to setpoint (response alarm)
3
Alarm at power-up(e.g. after power-down)
Alarm Info
Type
Access
Range
FlowDDE
ProPar
Modbus
Unsigned char
R
0…255
28
1/20
0x0034/53
This parameter provides information about the event type(s) that triggered an alarm situation. The value is a bitwise summation
of the issued alarm types; convert the value to binary to see which types are issued. The following alarm types can be issued:
Bit
Value
Type
Description
0
1
Error
Error flag raised
1
2
Warning
Warning flag raised
2
4
Minimum alarm
Measure < Alarm minimum limit
3
8
Maximum alarm
Measure > Alarm maximum limit
4
16
Batch counter alarm
Batch counter reached its limit
5
32
· This bit only: Power-up alarm
Alarm possibly caused by a power dip
· If combined with bit 2 or 3:
Response alarm
Difference between Measure and Setpoint too big
6
64
Master/slave alarm
Setpoint out of limits (caused by Slave factor)
7
128
Hardware alarm
Hardware error
Alarm Delay Time
Type
Access
Range
FlowDDE
ProPar
Modbus
Unsigned char
RW
0…255
182
97/7
0x0C27/3112
This value represents the time in seconds the alarm action will be delayed when an alarm limit has been exceeded. This value
also delays the alarm off action if an alarm limit is no longer exceeded.
Default value = 0.
Alarm Maximum Limit
Type
Access
Range
FlowDDE
ProPar
Modbus
Unsigned int
RW
0…32000
116
97/1
0x0C21/3106
Maximum limit for Measure to activate the maximum alarm situation (after Alarm Delay Time). Range 0…32000 represents 0…
100% signal. Alarm Maximum Limit must be greater than Alarm Minimum Limit.
Default value: 0.
Alarm Minimum Limit
Type
Access
Range
FlowDDE
ProPar
Modbus
Unsigned int
RW
0…32000
117
97/2
0x0C22/3107
Minimum limit for Measure to activate the minimum alarm situation (after Alarm Delay Time). Range 0…32000 represents 0…
100% signal. Alarm Minimum Limit must be smaller than Alarm Maximum Limit.
Default value: 0.

## Page 32

Bronkhorst®
Instruction Manual FLEXI-FLOW™ Compact
9.17.158I
32
Alarm Setpoint Mode
Type
Access
Range
FlowDDE
ProPar
Modbus
Unsigned char
RW
0…1
120
97/5
0x0C25/3110
Specifies whether or not to change the setpoint after an alarm situation is activated.
Value
Description
0
No setpoint change (default)
1
Change setpoint to Alarm new setpoint
Alarm New Setpoint
Type
Access
Range
FlowDDE
ProPar
Modbus
Unsigned int
RW
0…32000
121
97/6
0x0C26/3111
New (safe) setpoint during an alarm until reset. Range 0…32000 represents 0…100% setpoint.
Default value: 0
Reset Alarm Enable
Type
Access
Range
FlowDDE
ProPar
Modbus
Unsigned char
RW
0…15
156
97/9
0x0C29/3114
Available reset methods. The value is a bitwise summation of the enabled methods; convert the value to binary to see which
methods are enabled.
Default value: 15 (all bits/methods enabled)
The following methods are supported:
Bit
Value
Description
0
1
By hardware switch (if present)
1
2
Externally (obsolete)
2
4
By parameter Reset
3
8
Automatically (when alarm conditions no longer apply)
4.3.3
Counter
· Counter settings are most easily accessible using Bronkhorst FlowSuite, FlowPlot or FlowView or a Bronkhorst®
readout and control unit.
· When the instrument is powered down, it remembers the state of the counter. If the counter is active when the
instrument is powered down, it continues counting after powering on again.
Counter Mode
Type
Access
Range
FlowDDE
ProPar
Modbus
Unsigned char
RW
0…2
130
104/8
0x0D08/3337
Available modes:
Value
Description
0
Counter off (default)
1
Counting up continuously
2
Counting up until limit reached (set by Counter Limit)
Counter Unit
Type
Access
Range
FlowDDE
ProPar
Modbus
Unsigned char[4]
RW
see table
below
128
104/7
0xE838…0xE839/59449…59450
This parameter contains the name of the counter readout unit.

## Page 33

Bronkhorst®
Instruction Manual FLEXI-FLOW™ Compact
9.17.158I
33
Counter Unit supports the following values:
Mass
Normal volume
(1.01325 bar(a), 0 °C)
Standard volume
(1.01325 bar(a), 20 °C)
Custom volume
(Capacity Unit Pressure,
Capacity Unit Type
Temperature)
ug, mg, g, kg
uln, mln, ln,
mm3n, cm3n, dm3n, m3n
uls, mls, ls,
mm3s, cm3s, dm3s, m3s
ul, ml, l,
mm3, cm3, dm3, m3
Parameter Density
 (FlowDDE ID 170) is used to calculate Custom volume.
Counter Value
Type
Access
Range
FlowDDE
ProPar
Modbus
Float
RW
0…
10000000
122
104/1
0xE808…0xE809/59401…59402
Current counter value in units selected with parameter Counter Unit.
Counter Limit
Type
Access
Range
FlowDDE
ProPar
Modbus
Float
RW
0…
9999999
124
104/3
0xE818…0xE819/59417…59418
Counter limit/batch size in units selected with parameter Counter Unit.
Default value: 0.
Counter Setpoint Mode
Type
Access
Range
FlowDDE
ProPar
Modbus
Unsigned char
RW
0…1
126
104/5
0x0D05/3334
Specifies whether or not to change the setpoint after reaching the counter limit.
Value
Description
0
No setpoint change (default)
1
Change setpoint to Counter new setpoint
Counter New Setpoint
Type
Access
Range
FlowDDE
ProPar
Modbus
Unsigned int
RW
0…32000
127
104/6
0x0D06/3335
New (safe) setpoint when a counter limit is reached until reset. Range 0…32000 represents 0…100% setpoint.
Default value: 0
Reset Counter Enable
Type
Access
Range
FlowDDE
ProPar
Modbus
Unsigned char
RW
0…15
157
104/9
0x0D09/3338
Available reset methods. The value is a bitwise summation of the enabled reset methods; convert the value to binary to see
which methods are enabled.
Default value: 7 (bits/methods 0, 1 and 2 enabled)
38

## Page 34

Bronkhorst®
Instruction Manual FLEXI-FLOW™ Compact
9.17.158I
34
The following methods are supported:
Bit
Value
Description
0
1
By hardware switch (if present)
1
2
Externally (obsolete)
2
4
By parameter Reset
3
8
Automatically (e.g. when counter value is reset)
Totalizer Unit
Type
Access
Range
FlowDDE
ProPar
Modbus
Unsigned char[4]
RW
See
parameter
Counter Unit
394
104/18
0xE890…0xE891/59537…59538
This parameter contains the name of the totalizer readout unit.
Totalizer Value
Type
Access
Range
FlowDDE
ProPar
Modbus
Float
RW
0…
10000000
393
104/17
0xE888…0xE889/59529…59530
Current totalizer value in units as selected with parameter Totalizer Unit.
4.3.4
Network configuration
CAUTION
This section is included for reference only. Editing network settings should be done with Bronkhorst FlowSuite
.
Only if Bronkhorst FlowSuite is not available, follow these steps to prepare the instrument for the required communication
protocol:
1.
Set parameter Init Reset
 to value 64 to unlock secured parameters.
2.
Set parameter Fieldbus Interface Index to value 0 to select the fieldbus interface.
3.
Set parameter Fieldbus1 Selection to select the required communication protocol.
4.
Consult the manual for the applicable communication interface
 for information about assigning a node address or an IP
address to the instrument.
5.
Set parameter Init Reset
 to value 82 to lock secured parameters (or restart the instrument).
Fieldbus Interface Index
Type
Access
Range
FlowDDE
ProPar
Modbus
Unsigned char
RW
[0,5]
378
125/7
0x0FA7/4008
· Applicable communication interface (also see Bluetooth
)
· Value must be 0 before changing parameter Fieldbus1 Selection or address parameters.
· Default value: 0
Available interfaces:
Value
Description
0
Fieldbus
5
Bluetooth
27
45
11
45
42

## Page 35

Bronkhorst®
Instruction Manual FLEXI-FLOW™ Compact
9.17.158I
35
Fieldbus1 Selection
Type
Access
Range
FlowDDE
ProPar
Modbus
Unsigned char
RW B
[0…2]
305
125/8
0x0FA8/4009
· Selected communication protocol on the power and signal connector.
· Changes are effective immediately.
· The instrument only accepts values that match its hardware configuration (Ethernet/non-Ethernet, see table below).
· Default value (ex factory)
o non-Ethernet: 1
o Ethernet: 14
Available protocols:
Value
Description
NonEthernet
Ethernet
0
FLOW-BUS
ü
1
Modbus RTU
ü
2
ProPar
ü
11
EtherCAT®
ü
14
PROFINET
ü
18
POWERLINK
ü
19
EtherNet/IP™
ü
20
Modbus TCP
ü
4.3.4.1
Node address settings
· On instruments with no Ethernet interface, setting the manual address selector
 to a value other than 0
overrides the digital node address setting.
· Changes made to the node address settings will not be restored by a factory reset.
· Although each communication channel
 represents an individual instrument, all three communication channels
of the FLEXI-FLOW have the same node address.
· For protocol specific address settings, refer to the manual for the respective communication protocol
.
Fieldbus1 Address
Type
Access
Range
FlowDDE
ProPar
Modbus
Unsigned char
RW B
0…255
199
125/10
0x0FAA/4011
Fieldbus1 Baud Rate
Type
Access
Range
FlowDDE
ProPar
Modbus
Unsigned long
RW B
0…1.0E10
201
125/9
0xFD48…0xFD49/64841…64842
Fieldbus1 Parity
Type
Access
Range
FlowDDE
ProPar
Modbus
Unsigned char
RW B
0…2
335
125/12
0x0FAC/4013
The following values are supported:
Value
Description
0
No parity
1
Odd parity
2
Even parity
8
21
11

## Page 36

Bronkhorst®
Instruction Manual FLEXI-FLOW™ Compact
9.17.158I
36
Default settings
Network configuration is done ex factory as ordered. The table below shows the supported settings for the available
communication protocols.
Notes:
· Default settings are printed in bold.
· The node address can only be set by means of the digital parameters for the communication protocols for which default
values are indicated. For other communication protocols, use the address selectors on the instrument (see Changing fieldbus
settings (Ethernet)
).
Protocol
FLOW-BUS
Modbus RTU
POWERLINK
Address
3…125
1…247
1…239
Baud Rate
187500
9600
19200
38400
56000
57600
115200
n/a
Parity
0
0, 1, 2
n/a
4.3.4.2
IP address settings
· After changing IP address settings, restart the instrument to apply the changes.
· For protocol specific address settings, refer to the manual for the respective communication protocol
.
Fieldbus1 IP Address
Type
Access
Range
FlowDDE
ProPar
Modbus
String
RW B
390
125/14
0xFD70…0xFD77/64881…64888
Fieldbus1 Subnet Mask
Type
Access
Range
FlowDDE
ProPar
Modbus
String
RW B
391
125/15
0xFD78…0xFD7F/64889…64896
Fieldbus1 Gateway Address
Type
Access
Range
FlowDDE
ProPar
Modbus
String
RW B
392
125/16
0xFD80…0xFD87/64897…64904
4.3.5
Fluid set
Fluid Set Index
Type
Access
Range
FlowDDE
ProPar
Modbus
Unsigned char
RW
0…7
24
1/16
0x0030/49
With this parameter, any of the pre-configured fluids (up to 8) can be selected. Each fluid has its specific (configurable)
properties, such as Fluid Name, Capacity, etc.
Default value: 0 (fluid 1).
Note that the selected value is equal to the fluid number minus 1 (value 0 corresponds to fluid 1, value 1 to fluid 2, etc.)
Fluid Name
Type
Access
Range
FlowDDE
ProPar
Modbus
Unsigned char[10]
RW B
-
25
1/17
0x8188…0x818C/33161…33165
This parameter contains the name of the selected fluid.
19
11

## Page 37

Bronkhorst®
Instruction Manual FLEXI-FLOW™ Compact
9.17.158I
37
Capacity 100%
Type
Access
Range
FlowDDE
ProPar
Modbus
Float
RW B
1E-10…
1E+10
21
1/13
0x8168…0x8169/33129…33130
· This parameter represents the 100 % readout/control value (span), expressed in the Capacity Unit of the selected fluid.
· Capacity 100% is scaled when Inlet Pressure, Fluid Temperature or Fluid Name is changed for the selected fluid.
Capacity Unit
Type
Access
Range
FlowDDE
ProPar
Modbus
Unsigned char[7]
RW B
see below
129
1/31
0x81F8…0x81FB/33273…33276
This parameter represents the unit in which Capacity 100% is expressed.
Available units:
Mass flow
Normal volume flow
(1.01325 bar(a), 0 °C)
Standard volume flow
(1.01325 bar(a), 20 °C)
Custom volume flow
(Capacity Unit Type Pressure,
Capacity Unit Type
Temperature)
ug/h, ug/min, ug/s,
mg/h, mg/min, mg/s,
g/h, g/min, g/s,
kg/h, kg/min, kg/s
uln/h, uln/min, uln/s,
mln/h, mln/min, mln/s,
ln/h, ln/min, ln/s,
ccn/h, ccn/min, ccn/s,
mm3n/h, mm3n/m,
mm3n/s,
cm3n/h, cm3n/m, cm3n/s,
m3n/h, m3n/min, m3n/s,
scfh, scfm, scfs,
sccm, slm
uls/h, uls/min, uls/s,
mls/h, mls/min, mls/s,
ls/h, ls/min, ls/s,
ccs/h, ccs/min, ccs/s,
mm3s/h, mm3s/m, mm3s/s,
cm3s/h, cm3s/m, cm3s/s,
m3s/h, m3s/min, m3s/s
ul/h, ul/min, ul/s,
ml/h, ml/min, ml/s,
l/h, l/min, l/s,
cc/h, cc/min, cc/s,
mm3/h, mm3/m, mm3/s,
cm3/h, cm3/m, cm3/s,
m3/h, m3/min, m3/s,
cfh, cfm, cfs
Because of the maximum string length (7 characters), some unit names are abbreviated, for instance mm3n/m
means mm3n/min.
Capacity Unit Type Temperature
Type
Access
Range
FlowDDE
ProPar
Modbus
Float
RW B
-273.15…
3.4E+38
245
33/10
0xA150…0xA151/41297…41298
This parameter defines a reference temperature for conversion of the measured mass flow to a volume flow. See also
parameters Capacity Unit and Counter Unit.
Capacity Unit Type Pressure
Type
Access
Range
FlowDDE
ProPar
Modbus
Float
RW B
0…3.4E+38
246
33/11
0xA158…0xA159/41305…41306
This parameter defines a reference pressure for conversion of the measured mass flow to a volume flow. See also parameters
Capacity Unit and Counter Unit.
4.3.5.1
Advanced fluid set parameters
Note that the parameters described in this section do not contain actual measurement values, but only fixed
reference values, which can be used for capacity calculations and conversions.

## Page 38

Bronkhorst®
Instruction Manual FLEXI-FLOW™ Compact
9.17.158I
38
Inlet Pressure
Type
Access
Range
FlowDDE
ProPar
Modbus
Float
RW B
0…3.4E+38
178
113/13
0xF168…0xF169/61801…61802
Upstream pressure of the selected fluid in bar(a)
Outlet Pressure
Type
Access
Range
FlowDDE
ProPar
Modbus
Float
RW B
0…3.4E+38
179
113/14
0xF170…0xF171/61809…61810
Downstream pressure of the selected fluid in bar(a).
Fluid Temperature
Type
Access
Range
FlowDDE
ProPar
Modbus
Float
RW B
-250…500
181
113/16
0xF180…0xF181/61825…61826
Temperature of the selected fluid in °C.
Density
Type
Access
Range
FlowDDE
ProPar
Modbus
Float
RW B
0…3.4E+38
170
33/21
0xA1A8…0xA1A9/41385…41386
Density of the selected fluid in kg/m3
Heat Capacity
Type
Access
Range
FlowDDE
ProPar
Modbus
Float
RW B
0…3.4E+38
250
113/18
0xF190…0xF191/61841…61842
Heat capacity of the selected fluid in J/kg·K
Thermal Conductivity
Type
Access
Range
FlowDDE
ProPar
Modbus
Float
RW B
0…3.4E+38
251
113/20
0xF1A0…0xF1A1/61857…61858
Thermal conductivity of the selected fluid in W/m·K
Viscosity
Type
Access
Range
FlowDDE
ProPar
Modbus
Float
RW B
0…3.4E+38
252
113/21
0xF1A8…0xF1A9/61865…61866
Dynamic viscosity of the selected fluid in Pa·s
4.3.5.2
Fluid mixture parameters
Mix Fraction Type
Type
Access
Range
FlowDDE
ProPar
Modbus
Unsigned char
RW B
0…2
346
126/4
0x0FC4/4037
Sets the fraction type of the mixture:
Value
Description
0
Volume fraction
1
Mass fraction
2
Mole fraction

## Page 39

Bronkhorst®
Instruction Manual FLEXI-FLOW™ Compact
9.17.158I
39
Mix Volume Temperature
Type
Access
Range
FlowDDE
ProPar
Modbus
Float
RW B
-250…500
347
126/5
0xFE28…0xFE29/65065…65066
Temperature of the mixture in °C. The value of this parameter is only relevant if Mix Fraction Type = 0.
Mix Volume Pressure
Type
Access
Range
FlowDDE
ProPar
Modbus
Float
RW B
0…3.4E+38
348
126/6
0xFE30…0xFE31/65073…65074
Pressure of the mixture in bar(a). The value of this parameter is only relevant if Mix Fraction Type = 0.
Mix Component Index
Type
Access
Range
FlowDDE
ProPar
Modbus
Unsigned char
RW
0…4
349
126/7
0x0FC7/4040
Index of the selected component of the mixture (max. 5 components).
Mix Component Fraction
Type
Access
Range
FlowDDE
ProPar
Modbus
Float
RWB
0…1
350
126/8
0xFE40…0xFE41/65089…65090
Mix fraction of the selected mix component (Mix Component Index). The value range corresponds to 0…100%. The sum of the all
mix fractions must be equal to 1.
If the value is 0, the next component slots are ignored.
Mix Component Fluid Name
Type
Access
Range
FlowDDE
ProPar
Modbus
Unsigned char[10]
RW B
-
351
126/9
0xFE48…0xFE4C/65097…65101
This parameter contains the fluid name of the selected mix component (Mix Component Index). This parameter may contain one
of two value types:
· Gas name, e.g. 'N2', 'He', 'C3H6 #2'.
· CAS Registry Number, e.g. '7727-37-9', '7440-59-7', '115-07-1'
If the parameter contains no name, the next component slots are ignored.
4.3.6
Master/slave configuration (FLOW-BUS)
Normally, there is no communication between the instruments in a fieldbus system. The FLOW-BUS protocol, however, provides
a feature to set up a master/slave relationship between two instruments. The typical behavior of a slave instrument is to
automatically set its own setpoint relative to the output (measurement value) of its master.
The output value of any instrument in a FLOW-BUS network is automatically available to all other instruments without extra
wiring. A slave instrument can also be a master to other instruments.
To set up a master/slave relationship between instruments, first determine which instrument should be the master and which
should be the slave, then set Control Mode of the slave instrument to ‘FLOW-BUS slave’ (value 2; also see parameter Control
Mode
).
The slave instrument polls the output value of its master periodically and uses the slave factor to set its own setpoint relative to
the master's.
To prevent damage to the instruments an/or the system(s) they are connected to, be sure to avoid circular references
between devices on the same fieldbus. The FLOW-BUS system has no protection mechanism to prevent circular
references.
46

## Page 40

Bronkhorst®
Instruction Manual FLEXI-FLOW™ Compact
9.17.158I
40
Master Node
Type
Access
Range
FlowDDE
ProPar
Modbus
Unsigned char
RW
1…128
158
33/14
n/a
Sets the master node for the instrument.
Note that this parameter is only effective in a FLOW-BUS network (RS-485).
Slave Factor
Type
Access
Range
FlowDDE
ProPar
Modbus
Float
RW
0…500
139
33/1
0xA108…0xA109/41225…41226
The controller output from the master instrument is multiplied by Slave Factor/100 % to get the slave instrument setpoint.
In systems other than FLOW-BUS, Slave Factor is effective only if Control Mode is set to 'Analog slave', and the analog output
signal of the master instrument is redirected to the input of the slave instrument.
Example:
· master output = 80 %
· Slave Factor = 50
_ slave instrument setpoint = 80 % x 50 %/100 % = 40 %
4.3.7
Shut-off valve settings (FF-annS only)
This section only applies to FLEXI-FLOW models with an integrated shut-off valve (FF-annS).
Upon delivery, actuation of the shut-off valve is linked to the instrument setpoint: the valve is closed as long as setpoint = 0 and
open when setpoint > 0.
In Bronkhorst FlowSuite, the default behavior can be reprogrammed to operate the valve manually. Manual operation is then
carried out using parameter IO Switch Status.
Only if Bronkhorst FlowSuite is not available, follow these steps to modify the operating mode of the shut-off valve via digital
communication:
1.
Set parameter Actuator Index to value 1 to select the shut-off valve for adjustment.
2.
Set parameter Actuator Type to select the operating mode to manual control.
Notes:
· Make sure the operating mode matches the shut-off valve function (N.C. or N.O.), otherwise the the shut-off valve
will close when the control valve is open and vice versa.
· The shut-off valve responds to IO Switch Status only if the operating mode is set to Manual (Actuator Type 5 or 6).
Actuator Index
Type
Access
Range
FlowDDE
ProPar
Modbus
Unsigned char
RW
0, 1
433
114/0
0x0E40/3649
This parameter selects the instrument valve for reprogramming. Supported values:
Value
Description
0
Control valve
1
Shut-off valve

## Page 41

Bronkhorst®
Instruction Manual FLEXI-FLOW™ Compact
9.17.158I
41
Actuator Type
Type
Access
Range
FlowDDE
ProPar
Modbus
Unsigned char
RW
See below
80
114/6
0x0E46/3655
This parameter sets the operating mode of the selected valve. Make sure the operating mode matches the shut-off valve
function (N.C. or N.O.), otherwise the the shut-off valve will close when the control valve is open and vice versa.
Supported values:
Value
Operating mode
5
Manual, N.C.
6
Manual, N.O.
7
Automatic, N.C.
8
Automatic, N.O.
255
Disabled
IO Switch Status
Type
Access
Range
FlowDDE
ProPar
Modbus
Unsigned long
RW
See below
288
114/31
0xF2F8…0xF2F9/62201…62202
This parameter actuates the shut-off valve, but only if its operating mode is set to Manual (parameter Actuator Type). Depending
on the valve type, actuation opens or closes it:
Actuation
Normally
open
Normally
closed
Inactive
open
closed
Active
closed
open
The value of IO Switch Status is a bitwise summation of 2 function settings; convert the decimal value to binary to see the status
of each bit. To activate one or both bits, write the sum of their decimal (or hex) values to the register.
Parameter IO Switch Status supports the following settings (other bits are ignored):
Bit
Function
Value
Description
0
Actuation switch
0
Valve inactive (not powered)
1
Valve active (powered)
8
Observe or ignore
instrument safe state*
0
Observe default/safe state; actuation disabled if the instrument is in
default/safe state.
256
Ignore default/safe state; shut-off valve actuation enabled even if the
instrument is in default/safe state.
*) See parameter Special parameters - Control Mode
.
· Immediately after powering-up, both bits are inactive.
· In the event of communication faults, the shut-off valve will assume its default state
 (regardless of the value of
bit 8).
4.3.8
Device identification
User Tag
Type
Access
Range
FlowDDE
ProPar
Modbus
Unsigned char[16]
RW
-
115
113/6
0xF130…0xF137/ 61745…61752
With this parameter, the instrument can be given a custom tag name, with a maximum of 16 characters.
46
24
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

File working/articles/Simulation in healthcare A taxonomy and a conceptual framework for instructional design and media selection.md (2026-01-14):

# Simulation in healthcare  A taxonomy and a conceptual framework for instructional design and media selection

## Page 1

Medical Teacher
ISSN: 0142-159X (Print) 1466-187X (Online) Journal homepage: www.tandfonline.com/journals/imte20
Simulation in healthcare: A taxonomy and a
conceptual framework for instructional design
and media selection
Gilles Chiniara, Gary Cole, Ken Brisbin, Dan Huﬀman, Betty Cragg, Mike
Lamacchia, Dianne Norman & Canadian Network For Simulation In
Healthcare, Guidelines Working Group
To cite this article: Gilles Chiniara, Gary Cole, Ken Brisbin, Dan Huﬀman, Betty Cragg, Mike
Lamacchia, Dianne Norman & Canadian Network For Simulation In Healthcare, Guidelines
Working Group (2013) Simulation in healthcare: A taxonomy and a conceptual framework
for instructional design and media selection, Medical Teacher, 35:8, e1380-e1395, DOI:
10.3109/0142159X.2012.733451
To link to this article:  https://doi.org/10.3109/0142159X.2012.733451
Published online: 02 Nov 2012.
Submit your article to this journal
Article views: 22675
View related articles
Citing articles: 57 View citing articles
Full Terms & Conditions of access and use can be found at
https://www.tandfonline.com/action/journalInformation?journalCode=imte20

## Page 2

2013
2013; 35: e1380–e1395
WEB PAPER
Simulation in healthcare: A taxonomy and a
conceptual framework for instructional design
and media selection
GILLES CHINIARA1, GARY COLE2, KEN BRISBIN3, DAN HUFFMAN3, BETTY CRAGG4, MIKE LAMACCHIA5,
DIANNE NORMAN6 & CANADIAN NETWORK FOR SIMULATION IN HEALTHCARE, GUIDELINES WORKING
GROUP
1Universite´ Laval, Canada, 2Royal College of Physicians and Surgeons of Canada, 3Alberta Health Services eSIM North,
Canada, 4University of Ottawa, Canada, 5Shock Trauma Air Rescue Society, Canada, 6McMaster Children’s Hospital,
Canada
Abstract
Background: Simulation in healthcare lacks a dedicated framework and supporting taxonomy for instructional design (ID) to
assist educators in creating appropriate simulation learning experiences.
Aims: This article aims to fill the identified gap. It provides a conceptual framework for ID of healthcare simulation.
Methods: The work is based on published literature and authors’ experience with simulation-based education.
Results: The framework for ID itself presents four progressive levels describing the educational intervention. Medium is the mode
of delivery of instruction. Simulation modality is the broad description of the simulation experience and includes four modalities
(computer-based simulation, simulated patient (SP), simulated clinical immersion, and procedural simulation) in addition to mixed,
hybrid simulations. Instructional method describes the techniques used for learning. Presentation describes the detailed
characteristics of the intervention.
The choice of simulation as a learning medium is based on a matrix of simulation relating acuity (severity) to opportunity
(frequency) of events, with a corresponding zone of simulation. An accompanying chart assists in the selection of appropriate
media and simulation modalities based on learning outcomes.
Conclusion: This framework should help educators incorporate simulation in their ID efforts. It also provides a taxonomy to
streamline future research and ID efforts in simulation.
Background
Simulation in healthcare is increasingly being used for teaching
and training in health care, not only in technical skills and
patient management but also in competencies related to
patient safety and teamwork, a more novel yet increasingly
important use of simulation (Raemer 2004).
Although rapidly growing, there are still significant gaps in
the empirical evidence related to a wide variety of questions
surrounding the methodologies, the value, and the outcomes of
simulation in healthcare (Cook et al. 2011). This evidence gap
becomes a particular challenge when faculty, clinicians, and
educators are asked to integrate simulation into existing
curricula and training programs. Furthermore, in a context in
which simulation is being considered for use in national
licensure examinations, alignment between simulation centers
and programs in curriculum design is desirable. Hence, an
appropriate framework must be made available to purveyors of
simulation-based
training.
The
Canadian
Network
for
Simulation in Healthcare (CNSH) believes that the design of
such a framework must be based on a comprehensive
instructional
framework
that
supports,
as
a
minimum
Practice points
. Simulation in healthcare is not a monolithic concept and
includes vastly different educational experiences.
. An educational activity using healthcare simulation can
be described through a framework consisting of four
levels:
instructional
medium,
simulation
modality,
instructional method, and presentation.
. The ‘‘zone of simulation matrix’’ identifies those events
that are best adapted for simulation learning.
. The
framework
identifies
four
different
simulation
modalities: procedural simulation, computer-based simulation, simulated clinical immersion, and SP, with the
added methodology of hybrid simulations. Each is best
suited for specific competency domains or learning
outcomes.
. ‘‘Presentation’’ describes the low-level details that can
affect the design of an educational activity. It includes
elements related to feedback, fidelity (realism), choice of
simulator type, scenario design, and team composition.
Correspondence: Gilles Chiniara, Centre Apprentiss, Universite´ Laval, 1050, Avenue de la Me´decine, Pavillon Ferdinand-Vandry, local 3770-F,
Que´bec, QC G1V 0A6, Canada. Tel: (418) 656-2131, ext. 3902; fax: (418) 656-7747; email: Gilles.Chiniara@fmed.ulaval.ca
e1380
ISSN 0142–159X print/ISSN 1466–187X online/13/081380–16  2013 Informa UK Ltd.
DOI: 10.3109/0142159X.2012.733451

## Page 3

requirement, an alignment of unidisciplinary and/or interprofessional educational methodologies, definitions, theories, and
best practices that can, in turn, support a more universal
direction for research and research outcomes.
With the field still in its infancy, there has been no formal
theory of instructional design (ID) for simulation in healthcare.
Moreover, while theoretical frameworks that relate educational
methods to desired objectives do exist, none is specifically
designed for simulation in healthcare. There are some frameworks tailored to specific types of simulations, such as
computerized screen-based simulations (Williams 2003), that
are outside the field of healthcare. Most of the existing and
accepted ID theories either do not take the specifics of
simulation into consideration (such is the case with Kern
et al.’s (2009) six-step approach to curriculum development),
or use simulation as one single, very broad category, for
example, in Robert Gagne´’s principles of ID (Gagne´ et al.
2005). It is thus challenging to implement these theories for the
design of simulation curricula in learning institutions. Such
concerns have presumably hampered local efforts to build
appropriate and effective curricula for simulation in healthcare.
A crucial issue when discussing ID is to clearly distinguish
the tools used for learning from the actual educational
modalities. In simulation, more than in any other field, this
has been a persistent problem in the discussions and publications on simulation training and education. The actual tool
that is the patient simulator is often considered an educational
method, even though it might be used in widely different
educational
experiences,
for
example
to
reproduce
an
encounter with a patient (Lee et al. 2003; Hassan & Sloan
2006), to simulate an adverse event in a dynamic environment
(Kobayashi et al. 2006), or to facilitate training in a single
technique (Monti et al. 1998).
In this article, we propose a conceptual framework for the
ID of educational activities using simulation in healthcare. The
framework is linked to learning outcomes and assists educators in selecting characteristics for the best design of simulation
training interventions. It positions simulation within the
breadth of potential uses. This article also provides a model
for selecting appropriate simulation modalities, inspired by
Robert Gagne´’s extensive work on instructional media selection (Reiser & Gagne´ 1983; Gagne´ & Medsker 1996).
A definition of healthcare simulation
Although simulation in healthcare is not a monolithic concept,
the expression ‘‘healthcare simulation’’ seems appropriate to
describe the wide range of simulation experiences. Healthcare
simulation is an instructional medium used for education,
assessment, and research, which includes several modalities
that have in common the reproduction of certain characteristics of clinical reality. Simulation-based educational activities
rely on experiential learning. As a fundamental requirement,
they must allow participants to affect, to different degrees, the
course of the educational experience through verbal or
physical
interaction
with
the
simulated
components
or
patients.
The scope of the framework presented in this article is
restricted by excluding certain simulation modalities that target
healthcare systems rather than healthcare providers (e.g.,
computer simulations of emergency room patient flow for bed
management purposes).
A framework for ID
The framework for ID in healthcare simulation is based in
part on Cook’s model for research on e-learning (Cook 2005).
Its purpose is to provide a solid foundation on which to
build the characteristics of simulation for a given educational
intervention.
This framework describes an educational activity or intervention using four levels of ID (Figure 1). Each consecutive
level encompasses a defined set of characteristics that correspond to one level of details of the simulation activity. Stated
otherwise, an educational activity consists of several characteristics grouped into distinct levels based on their specific
impact on the overall quality and design of the intervention.
The choices for any characteristic at a given detail level usually
depend on the choices made at the previous levels. At each
level, the choices made are dependent on the actual learning
needs and goals of the activity.
Level 1: Medium
The most encompassing level, medium constitutes the most
basic choice in the ID process. It describes the principal mode
of delivery of instruction (Cook 2005), which determines all
the educational characteristics of the activity. Examples of
media include textbook learning, lectures, and computerbased training. Within this framework, simulation constitutes
one specific medium. Two of its core characteristics, the
imitation of reality and its interactive nature, distinguish it from
the other delivery media (McGuire 1999).
While simulation methodologies have the potential to
support virtually any learning opportunity, they are an
expensive and often scarce medium. Judiciously selecting
simulation as an appropriate medium for a given educational
activity entails an examination of specific characteristics of
that activity, which can be defined in a ‘‘zone of simulation
matrix.’’
The Zone of Simulation Matrix
The decision to use simulation as an instructional medium
should be based on the analysis of two characteristics of the
specific events, series of events or conditions that are the
desired focus of training: acuity and opportunity. Acuity is
defined as the potential severity of an event or a series of
events
and
their
subsequent
impact
on
the
patient.
Opportunity is defined as the frequency in which a particular
department or individual is actively involved in the management of the event. Alternatively, it also includes the likelihood
of discovering a particular problem. A latent problem that is
not easily discovered in the actual setting is akin to an event
that rarely occurs.
These two characteristics define a matrix that can be
divided into four quadrants: high-acuity low-opportunity
(HALO), high-acuity high-opportunity (HAHO), low-acuity
A framework for simulation in healthcare
e1381

## Page 4

low-opportunity (LALO), and low-acuity high-opportunity
(LAHO) (Figure 2). HALO encompasses clinical situations
that have a high potential to severely impact the patient but are
not common occurrences among the targeted group of
learners. Examples of HALO would be the management of
malignant hyperthermia in the operating room (OR), or a mass
casualty
incident
in the emergency
department. HAHO
includes clinical situations that have a high potential to
severely impact the patient but are common occurrences
among the targeted group. Examples of HAHO include
managing a postpartum hemorrhage in a postpartum unit,
and initiating cardiopulmonary bypass in the OR. LALO
includes clinical situations that have a lower potential to
severely impact the patient but are not a common occurrence
among the targeted group. An example of LALO is manual
disimpaction of fecal mass. Finally, LAHO involves clinical
situations that have a lower potential to severely impact the
patient if not managed appropriately and are common
occurrences among the targeted group. Examples of LAHO
include many of the tasks related to routine patient care and
uncomplicated induction of anesthesia in the OR.
The ‘‘zone of simulation’’ is that area in which simulation
may be advantageous over other instructional media. Within
this zone, simulation can serve as an acceptable substitute or
complement to other, less expensive, media and methods. The
zone of simulation encompasses all HALO situations, and,
when feasible, most HAHO and LALO situations (Figure 2).
While simulation could be used for acquiring introductory
skills in LAHO situations, it is probably not the most efficient
method in that context.
Level 2: Simulation Modality
The second level (called ‘‘configuration’’ in Cook’s original
framework), describes the simulation modality used for
teaching and learning. The choice of modality determines
a broad set of characteristics that dramatically alter the
learning experience. As such, simulation modalities represent
Figure 1.
The levels of ID for an educational experience using healthcare simulation. Each progressive level constitutes the
building blocks for the level directly above it.
Figure 2.
The zone of simulation matrix. The model is based
on two characteristics of clinical situations, acuity (severity)
and opportunity (frequency) that define four areas of varying
dynamics. The zone of simulation identifies those situations
where healthcare simulation may be advantageous over other
instructional media.
G. Chiniara et al.
e1382

## Page 5

the high-level description of the simulation activity. Their
categorization provides clues to their adaptation for specific
learning outcomes (see section ID in simulation and the
outcomes of learning).
This description is based partly on the concept of the
‘‘immersive learning environment’’ that is often associated with
simulation. This concept can range from a focused application
such as the use of a virtual reality simulator, to a broad
spectrum of dynamic environments such as the replication of
an operating theatre or an emergency department. From an
instructional framework perspective, we have defined immersive learning as any situation which is highly interactive and
engages the learner in such a way that disbelief is suspended
and
the
learner
becomes
an
active
participant
in
the
experience.
The shortcoming of the above definition when applied to a
simulation instructional framework is that it does not reflect
that there is a broad spectrum of ‘‘degrees of immersion.’’ In
simulation, we frequently apply an experiential mode to
learning, as defined by Appelman (2004, p. 73): ‘‘Experiential
Modes (EMs) are components of a learning environment that
focus on the learner’s perception while experiencing any
experiential mode, and through a micro analysis bridges the
gap between instructional development and learner cognition.’’ Within simulation, we can extend Appelman’s definition
of modes to identify the various modalities used to deliver
simulation, and classify simulation modalities into four categories with an additional methodology of hybrid (or blended)
simulation (see Figure 3 and Table 1).
Computer-based simulation is a modality that allows the
user to interact with the simulation experience through the
screen-based interface of a computer. It can be used, for
example, to simulate encounters with patients that are
programmed to respond to user input. Simulated Patients
(SPs) are also a simulation modality that can be used to
replicate encounters with real patients (Bokken et al. 2008;
Cleland et al. 2009). They have been used for more than three
decades in medical education (Barrows 1993). With this
modality, elements of history taking, physical examination,
and clinical reasoning can be learned either using an actual
patient or a surrogate playing the role of an actual patient. The
encounter and behavior of the patient are often standardized
(hence the frequent denomination ‘‘standardized patients’’).
However, contrary to simulated clinical immersion, the environment does not affect to a large extent the way the
educational experience unfolds or the occurrence of specific
events. In fact, SPs can be used ‘‘in classrooms and in many
nonclinical areas’’ (Barrows 1993).
In simulated clinical immersion, the learners are exposed
to particular patient problems. Its distinctive characteristic,
however, is that the environment reproduces the actual clinical
or work environment. Interaction with a patient usually takes
place in a fashion similar to SPs, but the environment takes on
an important role in achieving the learning outcomes, or
affects directly the educational experience and the occurrence
of events. For example, the dynamic nature of the environment
and
high
data
flow
of
a
simulated
Emergency
Department can be taken advantage of to teach crisis
management in complex clinical settings; alternatively, an
equipment failure may be the trigger for a specific teaching
case in a simulated operating theatre. In simulated clinical
immersion, the environment can be real (using the actual
clinical setting) or simulated; it can further be small in scale –
reproducing, for example, a single operating room – or can
have a very large scope – a battlefield, a building or even a
city. Importantly, however, the concept of environment
includes not only the physical setting but also the equipment,
teammates, and other individuals involved in reproducing the
desired situation. It also includes elements necessary to the
way
it
is
perceived
and
experienced
(eventually
even
believed) by participants. Thus, simulated clinical immersion
Table 1.
Description of the simulation modalities that constitute
level 2 of the ID framework.
Simulation modality
Description
Computer-based
simulation
Simulation modality in which the user interacts
with the simulation through a screen-based
interface. It can be used for a variety of
learning outcomes.
Hybrid simulation
Simulation experience that combines two or
more simulation modalities.
Procedural
simulation
Simulation modality in which a simulator allows
training of specific psychomotor skills and
their associated procedures.
Simulated clinical
immersion
Simulation modality in which the environment,
real or simulated, plays an important role and
reproduces the actual clinical or work environment. The experience may involve actors,
patients or patient simulators. It is typically
used for training in patient management,
clinical diagnosis, and patient safety
competencies.
Simulated patient
Simulation modality in which an actor, a patient,
or a patient simulator plays the role of an
actual patient (also called standardized
patient). It is typically used for training in
patient management, clinical diagnosis and
affective objectives.
Figure 3.
The four simulation modalities, which are broad
descriptions of the simulation experience. Modalities show
areas of overlap that constitute hybrid simulations.
A framework for simulation in healthcare
e1383
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

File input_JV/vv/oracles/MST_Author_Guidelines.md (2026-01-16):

# MST Author Guidelines

**Journal:** Measurement Science and Technology (IOP Publishing)
**ISSN:** 0957-0233 (print), 1361-6501 (online)
**Target:** Special Issue - "Data-Centric Exploration and Explanation of Physical and Engineering Phenomena"
**Deadline:** March 31, 2026

---

## Scope Requirements

MST papers must:
1. **Advance measurement science** — not merely apply established techniques
2. **Include uncertainty analysis** — precision/accuracy of all measurements
3. **Demonstrate novelty** — clear statement of what's new (< 100 words)
4. **International relevance** — accessible to global readership

> "All submitted articles should contain consideration of the uncertainty, precision and/or accuracy of the measurements presented."

---

## Article Structure (IMRAD)

| Section | Requirements |
|---|---|
| **Title** | Concise, informative, include key terms |
| **Abstract** | Max 300 words, self-contained, no undefined acronyms |
| **Keywords** | 3-7 keywords required |
| **Introduction** | Background, novelty statement, relevance to measurement science |
| **Methods** | Sufficient detail for reproducibility |
| **Results** | Clear presentation of findings |
| **Discussion** | Significance, comparison with prior work |
| **Conclusion** | Novelty summary, future directions |
| **Acknowledgements** | Funding, conflicts of interest |
| **Data Availability** | Statement required |

---

## Formatting

### General
- No strict page limit (check specific requirements)
- Single or double column accepted
- LaTeX (iopart.cls) or Word accepted
- Consistent spelling/hyphenation throughout

### Mathematics
- Punctuate equations as part of sentences
- Roman for: d (differential), e (exponential), i (complex), trig functions
- Units: m s⁻¹ format with space between value and unit
- Numbers: thin space every 3 digits (15 000)

### Figures
- Vector format preferred (EPS or PDF)
- Text size: 8-12 pt at final size
- Avoid color as sole information carrier
- Sequential numbering
- Multi-part: label as (a), (b), etc.
- Caption must be self-explanatory

### Tables
- Place at page top
- Number sequentially
- Footnotes: lowercase superscript letters

### References
- Vancouver (numerical) OR Harvard (alphabetical) — be consistent
- Include DOIs when available
- Complete bibliographic information required

---

## Data Availability

- Supplementary files: up to 50 MB each (150 MB total)
- Large datasets: use external repository (Zenodo, Figshare, etc.)
- Unique DOIs assigned to supplementary material
- Data availability statement required

---

## Submission

- Via ScholarOne: https://mc04.manuscriptcentral.com/mst-iop
- Double-anonymous review option available (use `[anonymous]` class option)

---
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

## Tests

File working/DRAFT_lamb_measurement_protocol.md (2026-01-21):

# DRAFT: Lamb Chest Compression Measurement Protocol

**Status:** DRAFT - for discussion only
**Purpose:** Characterize infant-surrogate chest mechanical properties
**Collaborator:** Arjen ten Pas (LUMC)
**Created:** 2026-01-18

---

## Objective

Measure force-displacement characteristics of lamb chest to establish reference data for infant CPR manikin fidelity assessment.

**Target parameters:**
- Stiffness k (N/mm)
- Damping coefficient c (N·s/mm)
- Non-linearity
- Hysteresis

---

## Background: Animal Models

| Model | Primary use | Chest mechanics |
|---|---|---|
| **Piglet** | CPR/compression studies | Similar to infant |
| **Lamb** | Ventilation/fetal transition | Different geometry |

**Why lamb (not piglet)?**
- LUMC (Arjen ten Pas) has lamb infrastructure for neonatal resuscitation research
- Lambs used for fetal-to-neonatal transition studies
- ~3.5 kg weight matches term infant
- Opportunity for collaboration

**Caveat:** Piglet chest mechanics may be more directly comparable to human infant. Lamb chest geometry differs. Results should be interpreted with this in mind.

**Question for Arjen:** Are compression forces typically measured on lambs at LUMC, or only ventilation parameters?

---

## Animal Specifications

| Parameter | Target | Rationale |
|---|---|---|
| Species | Lamb | Similar mass to term infant |
| Weight | 3-4 kg | Matches infant manikin target |
| Age | Newborn/perinatal | Chest compliance comparable |

---

## Equipment

### Available (home lab → transport to LUMC via trailer)
- CNC linear actuator (BlackBox X32)
- Load cell DYMH-103 (0-49 N)
- Displacement sensor VL53L4CD
- STM32F405 data acquisition

### To prepare
- ~~Compression plunger (~30 mm diameter, flat or slightly curved)~~ **AVAILABLE:** `Compression Actuator extension.stl` (20mm diameter, see `hardware/`)
- Positioning support/jig
- Calipers for chest measurement
- Power supply / extension cables for LUMC setup

**Actuator note:** 20mm diameter matches two-thumb contact area and Schmölzer 2023 mechanical CC design.

### Backup: Portable IMU setup (if CNC impractical)
- Bosch BHI360 IMU (6-axis + sensor fusion)
- Requires pre-validation against CNC reference
- Only if space/power constraints at LUMC

---

## Measurements to Record

### Per animal:
| Parameter | Unit | Method |
|---|---|---|
| Weight | kg | Scale |
| Chest AP diameter | mm | Calipers |
| Age | days | Record |
| Post-mortem interval | hours | Record |
| Temperature | °C | Thermometer |

### Per compression test:
| Parameter | Unit | Rate |
|---|---|---|
| Force | N | 100 Hz |
| Displacement | mm | 100 Hz |
| Timestamp | ms | Synchronized |

---

## Test Protocol (Draft)

### Preparation
1. Position lamb supine
2. Measure chest AP diameter
3. Calculate target depth: 1/3 × AP diameter
4. Zero sensors

### Test 1: Quasi-static (stiffness)
- Compression rate: 2 mm/s
- Depth: 0 → target → 0
- Cycles: 3
- Rest: 30 s between cycles

### Test 2: Dynamic (damping)
- Compression rate: 100/min (~1.7 Hz)
- Depth: target depth
- Cycles: 10
- Rest: 60 s after

### Test 3: Repeat quasi-static
- Same as Test 1
- Check for tissue fatigue/change

---

## Data Analysis

### Stiffness (from quasi-static):
```
k = ΔF / Δd  (linear fit)
```
Or polynomial fit for non-linearity:
```
F = k₁d + k₂d² + k₃d³
```

### Damping (from dynamic):
```
c = loop_width / (2 × v_max)
```

### Hysteresis:
```
H = (loop_area / loading_area) × 100%
```

---

## Sample Size

| Phase | n | Purpose |
|---|---|---|
| Pilot | 2-3 | Verify setup, refine protocol |
| Main study | 8-10 | Reference data with CI |

---

## Considerations

### Ethical
- [ ] Animal research approval required
- [ ] LUMC protocol coverage?

### Practical
- [ ] Fresh tissue timing (<2h post-mortem ideal)
- [ ] Temperature control
- [ ] Equipment transport to LUMC?

### Scientific
- [ ] Live vs post-mortem differences (Arbogast: ~2× stiffer post-mortem)
- [ ] Lamb vs human infant validity

---

## Open Questions

1. Does LUMC have existing ethical approval for lamb mechanical testing?
2. Can we use animals from other studies (opportunistic)?
3. ~~Equipment at LUMC or transport from HAN?~~ **RESOLVED: Transport CNC to LUMC via trailer**
4. Fresh post-mortem or anesthetized?
5. Sample size for statistical validity?
6. Space/power requirements at LUMC for CNC setup?

---

## Next Steps (if proceeding)

1. [ ] Discuss feasibility with Arjen ten Pas
2. [ ] Clarify ethical/practical constraints
3. [ ] Pilot test (n=2-3)
4. [ ] Refine protocol based on pilot
5. [ ] Main study (n=8-10)

---

*DRAFT - not for execution without further review*

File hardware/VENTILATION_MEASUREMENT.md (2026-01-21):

# Ventilation Measurement Apparatus

## Airway Tubing Sizes

| ID | Typical use |
|----|---|
| 4 mm | Small infant, neonatal |
| 6 mm | Infant |
| 8 mm | Pediatric |
| 22 mm | Adult (ISO standard) |

**Physiological reference:**
- Term neonate trachea: ~4-5 mm diameter
- Neonatal ETT (endotracheal tube): 3.0-3.5 mm ID

### Trade-off: 4 mm vs 6 mm

| Tubing | Pros | Cons |
|---|---|---|
| 4 mm ID | Realistic airway resistance | Fewer T-connector options, may need adapters for EL-PRESS |
| 6 mm ID | Easy to source T-connectors, matches EL-PRESS fittings | Slightly lower resistance than real infant airway |

**Recommendation:** Keep 4 mm for the manikin connection (physiological), use a short 4→6 mm adapter where you connect the sensors. This way:
- Manikin side: realistic resistance
- Sensor side: standard 6 mm fittings

---

## Sensors

| Sensor | Type | Range | Purpose |
|---|---|---|---|
| Bronkhorst EL-PRESS P-502C | Gauge pressure | 0-100 mbar (0-10 kPa) | Primary Paw measurement |
| MPXV5010GP ×2 | Gauge pressure | 0-10 kPa | Backup / blocked airway detection |
| SDP810 | Differential pressure | ±500 Pa | Flow measurement |

**Sensor port sizes:**
- EL-PRESS P-502C: 11 mm OD barbed fitting (needs ~10-11 mm ID tubing)
- MPXV5010GP: ~3 mm barbed port (2.8 mm nominal)

---

## T-Connectors Required

For tapping pressure from the airway circuit.

**Current tubing:** 4 mm ID (6 mm OD)

**Options:**
- Barbed T-connector, 4 mm ID
- 4→6 mm stepped adapter (to match EL-PRESS fittings)
- Luer-lock T-connectors (flexible, medical-grade)

**Suppliers:** Festo, SMC, RS Components, medical suppliers

---

## Suggested Measurement Setup

```
Manikin airway (4 mm ID)
      │
      ▼
   ┌──┴──┐
   │  T  │──── short tubing ──── EL-PRESS P-502C (primary Paw)
   └──┬──┘
      │
      ▼
   ┌──┴──┐
   │  T  │──── short tubing ──── MPXV5010GP (backup)
   └──┬──┘
      │
      ▼
  SDP810 (flow)
      │
      ▼
   Test lung / open
```

**Recommendation:** Keep 4 mm tubing at manikin connection (physiologically appropriate), use 4→6 mm adapter at sensor connections for easier fitting.

---

## To Order / Source

| Item | Qty | Purpose |
|---|-----|---|
| T-connector, 4 mm barbed | 2 | Tap pressure from airway |
| Reducer 4→10 mm (stepped adapter) | 1 | Adapt to EL-PRESS |
| Silicone tubing, 10-11 mm ID | ~10 cm | EL-PRESS connection |
| Reducer 4→3 mm | 1-2 | Adapt to MPXV5010GP |
| Silicone tubing, 4 mm ID | ~50 cm | Main airway |
| Silicone tubing, 3 mm ID | ~20 cm | MPXV5010GP connection |

**Alternative:** Luer-lock system with adapters for more flexibility.

---

*Last updated: 2026-01-21*

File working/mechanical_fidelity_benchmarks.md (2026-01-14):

# Mechanical Fidelity Benchmarks: Literature Review

**Date:** 2025-12-20
**Purpose:** Summarize available biomechanical data for CPR manikin mechanical fidelity requirements
**Context:** Supporting evidence for proposition paper on engineering fidelity

---

## 1. The Core Question

To validate that a manikin's mechanical response matches human physiology, we need **reference data** — biomechanical benchmarks from actual humans. This note summarizes what exists in the literature.

---

## 2. Adult Thorax Biomechanics

### 2.1 Stiffness Values

| Parameter | Value | Source |
|---|---|---|
| Human chest stiffness | **4–10 N/mm** (at 50mm depth) | Variable Stiffness Manikin Study, IEEE J-BHI 2024 |
| Human chest damping | 0.08–0.38 N·s/mm (at 30mm) | Same study |
| Commercial manikin range | 5.34–13.59 N/mm | Same study |

**Reference:** https://pmc.ncbi.nlm.nih.gov/articles/PMC11329213/

### 2.2 Force-Depth Relationship (Clinical CPR)

| Parameter | Value | Source |
|---|---|---|
| Mean applied force | 30.3 ± 8.2 kg (≈297 N) | Tomlinson et al. 2007 |
| Mean compression depth achieved | 42 ± 8 mm | Same study |
| Force required for 38mm depth | <50 kg (490 N) in 96% of patients | Same study |
| Force for guideline-compliant 50mm | 445–556 N (100–125 lbs) | Chest compression force study |

**Reference:** https://pubmed.ncbi.nlm.nih.gov/17141936/

### 2.3 Live vs Cadaver Comparison (Critical Finding)

| Condition | Force at 40mm Deflection | Source |
|---|---|---|
| Live CPR (perfused tissue) | **286 N** | Arbogast et al. 2006 |
| Post-mortem cadaver | **588 N** | Same study |

**Implication:** Live human tissue is significantly **softer** than cadaver tissue. Cadaver-based benchmarks may overestimate required stiffness.

**Reference:** https://pubmed.ncbi.nlm.nih.gov/17311162/

### 2.4 Non-Linear Behavior

Human chests exhibit:
- **Non-linear** force-displacement (stiffness increases with depth)
- **Hysteresis** (different loading vs unloading curves)
- **Viscoelastic** response (rate-dependent)

Most commercial manikins show **linear** spring behavior — this behavioral mismatch may be more significant than absolute stiffness values.

---

## 3. Manikin Characterization Data

### 3.1 Variable Stiffness Manikin (Resusci Anne QCPR)

| Spring Setting | Stiffness | Peak Force (1st min) | Depth Achieved |
|---|---|---|---|
| Soft | 0.6 kg/mm (5.9 N/mm) | 47.9 ± 16.2 kgf | 51.9 ± 7.6 mm |
| Standard | 0.9 kg/mm (8.8 N/mm) | 52.9 ± 12.7 kgf | 41.3 ± 11.4 mm |
| Hard | 1.2 kg/mm (11.8 N/mm) | 67.9 ± 14.9 kgf | 34.2 ± 11.5 mm |

**Reference:** https://pmc.ncbi.nlm.nih.gov/articles/PMC9573907/

### 3.2 Commercial Manikin Survey (Historical)

Force required at various depths across 8 manikin types:

| Depth | Force Range |
|---|---|
| 1 cm | 6.3–14 kp (62–137 N) |
| 2 cm | 11.6–30 kp (114–294 N) |
| 3 cm | 17–38 kp (167–373 N) |
| 4 cm | 22.5–54 kp (221–530 N) |
| 5 cm | 28.5–69 kp (280–677 N) |

**Key observation:** Spring-based manikins (Ambu Man, Resusci Anne) show linear behavior; foam-based (Little Anne) show decreasing resistance with depth.

**Reference:** https://www.sciencedirect.com/science/article/abs/pii/030095729500874S

### 3.3 Human vs Manikin Comparison

> "Human chests are stiffer (i.e., require greater force to compress a given distance) compared with manikin chests at chest compression depths of 1.5–2 inches."

**Implication:** Commercial manikins may be **too soft**, not too stiff — contrary to initial hypothesis.

---

## 4. Infant/Pediatric Data

### 4.1 What Exists

| Parameter | Value | Source |
|---|---|---|
| Optimal infant compression force | **3.8–4.3 kg (37–42 N)** | Two-thumb biomechanics study |
| Two-thumb technique force | 4.04 ± 1.83 kg | Same study |
| Two-finger technique force | 3.22 ± 1.11 kg | Same study |
| Target depth (infant) | ≥40 mm | AHA/ERC 2025 guidelines |
| Child (8-22y) force at max deflection | 309 ± 55 N | Maltese 2008 |

**Reference:** https://pubmed.ncbi.nlm.nih.gov/31633625/

### 4.2 The Critical Gap

> "No direct force-displacement curves for human neonates exist in literature."

Manikin stiffness for infants was determined by **expert opinion** — healthcare providers with pediatric CPR experience ranked manikins by "feel" and consensus determined "realistic" stiffness.

**Reference:** https://pubmed.ncbi.nlm.nih.gov/19699023/

**Implication:** There is no ground-truth biomechanical data for infant/neonate thorax. All infant manikin mechanical properties are based on subjective assessment, not objective measurement.

---

## 5. How Systematic Is Manikin Specification? (Critical Finding)

A key question: has manikin mechanical fidelity been established systematically, or ad hoc?

### 5.1 Two Contrasting Approaches

| Aspect | Aase et al. 2008 (Adults) | Tomlinson et al. 2009 (Pediatric) |
|---|---|---|
| **Method** | Patient-derived measurement | Expert consensus |
| **Sample** | 59 cardiac arrest patients | 63 healthcare providers |
| **Data collection** | Defibrillator with force sensor + accelerometer during real CPR | Subjective "feels like" assessment |
| **Output** | 8 interchangeable chest profiles covering measured human range | Consensus on which spring "feels right" |
| **Validation** | ±30 N or ±2 mm accuracy at 30-50mm depth | Kappa agreement statistics only |
| **Rigor** | **Systematic — metrologically validated** | **Ad hoc — no objective measurement** |

### 5.2 The Aase 2008 Approach (Gold Standard)

This is **the most rigorous approach found in the literature**:

1. **Measurement:** Chest stiffness and damping of 59 cardiac arrest patients measured during out-of-hospital CPR using instrumented defibrillator
2. **Translation:** Created manikins with 8 interchangeable force-depth profiles representing the measured range
3. **Validation:** Verified using same equipment; accuracy within ±30 N or ±2 mm between 30-50mm depth
4. **Result:** Manikins that demonstrably replicate human chest mechanics

**Reference:** https://pubmed.ncbi.nlm.nih.gov/18990635/

### 5.3 The Tomlinson 2009 Approach (Expert Opinion)

For pediatric manikins, the approach was **not systematic**:

1. **Sample:** Convenience sample of 63 international healthcare providers
2. **Method:** Experts performed compressions on manikins with varying spring stiffness, masked to settings
3. **Task:** Identify which manikin "most closely matched actual children they had treated"
4. **Agreement:**
   - Initial agreement: **43-46%** — barely above chance
   - After excluding "outlier" assessments: ~90%
5. **Validation:** None — no comparison to objective human data

**Critical limitation:** The study explicitly notes "further study is needed to evaluate whether enhanced manikin biofidelity will improve CPR performance" — acknowledging uncertainty about real-world validity.

**Reference:** https://pubmed.ncbi.nlm.nih.gov/19699023/

### 5.4 Summary: Specification by Population

| Population | Systematic Specification? | Method | Source |
|---|---|---|---|
| **Adult** | **Yes** | Patient-derived measurement (n=59) | Aase 2008 |
| **Child (5y)** | **No** | Expert opinion (43% initial agreement) | Tomlinson 2009 |
| **Infant (6mo)** | **No** | Expert opinion (46% initial agreement) | Tomlinson 2009 |
| **Neonate** | **No data found** | — | — |

### 5.5 No Regulatory Standard Exists

There is **no ISO or regulatory standard** for CPR manikin mechanical properties:

| Standard Body | Requirement | Covers Mechanical Fidelity? |
|---|---|---|
| **AHA 2019** | Instrumented feedback (depth, rate) | **No** — feedback only |
| **ISO** | No CPR manikin standard exists | N/A |
| **Manufacturers** | Self-specified | Variable, unvalidated |

### 5.6 Implication for Proposition Paper

This finding strengthens the argument:

> "For adult manikins, one research group (Aase 2008) demonstrated that systematic patient-derived specification is feasible — yet this approach has not been widely adopted. For pediatric and infant manikins — where excessive force risk is arguably highest — specifications rely solely on expert consensus with <50% initial agreement. No regulatory standard mandates mechanical characterization of any kind."

This supports calling for:
1. Adoption of patient-derived specification methodology (Aase approach)
2. Regulatory requirements for mechanical characterization
3. Research to establish pediatric/neonatal biomechanical benchmarks

---

## 6. Upper Bounds: Injury Thresholds

### 6.1 Rib Fracture Incidence

| Population | Fracture Incidence | Source |
|---|---|---|
| Adults | 55–97% | Systematic review 2024 |
| Children | 0–2% | Same review |

**Reference:** https://pmc.ncbi.nlm.nih.gov/articles/PMC11458643/

### 6.2 Maximum Recommended Parameters

| Parameter | Value | Source |
|---|---|---|
| Maximum depth (adult) | ≤60 mm (2.4 inches) | AHA 2020 |
| Commonly cited fracture threshold | ~60 lbs (270 N) | CPR injury literature |

**Reference:** https://link.springer.com/article/10.1007/s00068-024-02678-6

---

## 7. Derived Requirements (Proposed)

Based on available evidence, defensible mechanical fidelity boundaries:

### 7.1 Adult Manikin

| Dimension | Lower Bound | Upper Bound | Rationale |
|---|---|---|---|
| Stiffness | 4 N/mm | 10 N/mm | Human range at 50mm depth |
| Force at 50mm | 200 N | 500 N | Clinical CPR force data |
| Behavior | Non-linear | With hysteresis | Human tissue characteristic |
| Full recoil | Required | — | Guideline requirement |

### 7.2 Infant Manikin

| Dimension | Lower Bound | Upper Bound | Rationale |
|---|---|---|---|
| Force at 40mm | 30 N | 50 N | Two-thumb technique data |
| Depth achievable | ≥40 mm | — | AHA/ERC guidelines |
| Stiffness | Unknown | Unknown | **No human reference data exists** |

---

## 8. Implications for the Proposition Paper

### 8.1 Nuance Required

The original hypothesis suggested manikins are "too stiff" leading to excessive force habits. The evidence suggests a more nuanced picture:

1. **Absolute stiffness:** Commercial manikins may actually be **too soft**, not too stiff
2. **Behavioral mismatch:** The **linear vs non-linear** response difference may be more significant
3. **Infant gap:** No biomechanical ground truth exists — this strengthens the call for research

### 8.2 Reframing Options

**Option A: Emphasize behavioral fidelity**
> "Manikins exhibit linear spring behavior while human tissue shows non-linear viscoelastic response with hysteresis — this behavioral mismatch may be more significant than absolute stiffness values."

**Option B: Emphasize the measurement gap**
> "Neither stiffness nor behavioral response of commercial manikins has been validated against human biomechanical data — for infants, no such reference data even exists."

**Option C: Narrow scope to sensors**
> Acknowledge mechanical fidelity gap in discussion, but keep primary argument focused on sensor validity (where we have strong evidence: 5.6% shift, 120-130× deviation).

### 8.3 Recommendation

Given that:
- Sensor validity claims (H1-H2) have strong evidence from own work
- Mechanical fidelity claims (H5-H7) lack definitive human benchmarks
- The stiffness direction may be opposite to initial hypothesis

**Suggested approach:** Lead with sensor validity problem (strong evidence), acknowledge mechanical fidelity as an open question requiring further research, and call for establishment of biomechanical benchmarks as part of the paper's recommendations.

---

## 9. Key Sources

| Topic | Key Reference |
|---|---|
| Human stiffness range | PMC11329213 (IEEE J-BHI 2024) |
| Clinical force-depth | Tomlinson 2007 (Resuscitation) |
| Live vs cadaver | Arbogast 2006 (Stapp Car Crash J) |
| **Systematic adult specification** | **Aase 2008 (Resuscitation)** |
| Manikin characterization | PMC9573907 (Heliyon 2022) |
| Infant force data | PMC (JAHA 2020) |
| Infant stiffness (expert opinion) | Tomlinson 2009 (Resuscitation) |
| Rib fracture incidence | PMC11458643 (Eur J Trauma 2024) |

---

*Document created: 2025-12-20*
*Updated: 2025-12-20 — Added section on systematic vs ad-hoc specification*
*For discussion with: Supervisors/Colleagues*

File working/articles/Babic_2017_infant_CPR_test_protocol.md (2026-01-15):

# Development of a Test Protocol to Evaluate Infant CPR Training Manikins

**Authors:** Babic N, Baddour N, Fenech M (University of Ottawa)
**Venue:** IEEE MeMeA 2017
**DOI:** 10.1109/MeMeA.2017.7985839

---

## Abstract

The authors created a cross-platform LabVIEW program and test protocol using a Universal Testing Machine (UTM) to evaluate infant CPR manikin performance. They assessed thoracic force-displacement response and feedback mechanisms through root-mean-square error (RMSE) calculations, reporting compression scores of ±17 N, decompression of ±83 N, and final scores of ±50 N for their prototype.

---

## Key Quotes (for claim verification)

### Gap in infant data (supports C5):
> "Little research has been performed to evaluate the force required in younger infants"

> "the absence of well-documented test protocols for the evaluation of CPR manikins"

### Source of reference curves:
- Cite Maltese et al. (2008) for pediatric thoracic force-deflection — but this covers **8-22 year olds**, not infants
- For infants (<12 months), they used **scaling methods** from older child data

---

## Methods Summary

### Test Equipment
- Hydraulic Instron Model 1332 UTM
- Dynamic force capacity: minimum 500 N
- Calibrated load cells and stroke position sensors

### Data Acquisition
- LabVIEW-based
- 10 kHz sampling rate
- 50 data points/second/channel

### Protocol
1. Thoracic force-displacement evaluation via RMSE
2. Feedback mechanism calibration (visual/audio cues)
3. Scoring: compare experimental vs "theoretical" curves

### RMSE Formula
$$RMSE = \sqrt{\frac{\sum_{i=1}^{n}(\hat{y}_i - y_i)^2}{n}}$$

---

## Results

**Prototype manikin:** 7-month-old anthropometrics, ~12 cm max chest depth

**Performance:**
| Phase | RMSE Score |
|---|---|
| Compression | ±17 N |
| Decompression | ±83 N |
| Final | ±50 N |

- Force for 40 mm compression: **~190 N**
- Decompression showed "major deviation" due to excessive hysteresis

---

## Relevance to MST Paper

### Supports claim C5:
Babic explicitly acknowledges the absence of infant biomechanical reference data. Their "theoretically desired curves" are scaled from older child data, not measured from human infants.

### Comparison to Thielen 2017:

| Aspect | Babic 2017 | Thielen 2017 |
|---|---|---|
| Focus | Test protocol | Manikin design |
| Reference data | Scaled from 8-22y | None (anatomical approach) |
| Force at ~40mm | 190 N (prototype) | "Considerably lower" than human |
| Human infant validation | ❌ No | ❌ No |

### Your paper's contribution:
- Babic provides test *methodology* but lacks human infant reference envelope
- Your EFI framework provides what's missing: systematic comparison against reference model
- Even Babic's scaled curves are approximations — your ventilation data (Huang 2016) provides actual infant reference

---

## References Cited (relevant)

- Maltese et al. (2008): Pediatric thoracic force-deflection (8-22 years)
- Park et al. (2014): Manikin-integrated measurement systems
- Stanley et al. (2012): Programmable pneumatic damping

---

*Retrieved: 2026-01-15*
*Source: ResearchGate / IEEE Xplore*

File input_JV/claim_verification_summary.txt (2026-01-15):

CLAIM VERIFICATION SUMMARY
MST Paper: Engineering Fidelity of CPR Training Manikins
Date: 2026-01-15
Scope: Infant VENTILATION only (compression out of scope - no human stiffness/damping data)

==============================================================================
COVERAGE: 9/12 in-scope claims verified (75%)
P0 Critical: 6/7 verified (86%) - Remaining P0 blocked by own experiments
==============================================================================

SECTION 1: INTRODUCTION
-----------------------
[x] I2: No systematic manikin benchmark exists
    Source: Literature gap confirmed. Only Baubin 1995 (30y old). Recent work
    (Lim 2024, Morin 2024) develops single manikins, not benchmarks.

[x] I3: First infant ventilation reference model for manikin benchmarking
    Source: No competing infant ventilation manikin benchmark found.

SECTION 2: HUMAN REFERENCE MODEL - VENTILATION (IN SCOPE)
---------------------------------------------------------
[x] V1: Infant compliance ~78-171 mL/kPa (age-dependent)
    Source: Huang 2016 (n=205 infants, 1-96 weeks)
    Values: 1-24 wks: 77.95 +/- 46.16 mL/kPa
            73-96 wks: 170.58 +/- 50.14 mL/kPa

[x] V2: Infant resistance ~6.4-3.7 kPa/L/s (decreases with age)
    Source: Huang 2016 (n=205)
    Values: 1-24 wks: median 6.39 kPa/L/s
            73-96 wks: median 3.74 kPa/L/s

[x] V3: Infant chest wall ~3x more compliant than lungs
    Source: Stoecklin 2024 (n=23 preterm), Diedericks 2025 (review)
    Values: Ccw/kg 3.0 vs CL/kg 0.95 mL/cmH2O/kg
    Note: Ratio normalizes by ~1 year (rib ossification)

SECTION 7: DISCUSSION
---------------------
[x] D1: First systematic multi-manikin ventilation benchmark
    Source: Literature gap confirmed - no multi-manikin benchmark against
    human reference values exists

[x] D2: Ventilation fidelity is novel contribution
    Source: Reiss 2015 calls for manikin C/R characterization but none exists

==============================================================================
COMPRESSION - OUT OF SCOPE (verified but not benchmarkable)
==============================================================================
Why out of scope: No human stiffness/damping data exists for infants.
We have depth targets but cannot benchmark force-displacement behavior.

[x] C5: Infant chest properties largely uncharacterized
    Source: Babic 2017 - "Little research has been performed to evaluate
    the force required in younger infants"
    -> This GAP is why compression is out of scope

[x] C7: Infant compression depth targets exist (Japan 2024)
    Values: 0mo: 2.7cm, 2mo: 2.9cm, 12-23mo: 3.6cm
    Note: Depth only - no force/stiffness data to benchmark against

==============================================================================
CLAIMS BLOCKED BY OWN WORK (experiments pending)
==============================================================================
[ ] M1: Protocol based on IEEE TIM methodology
[ ] M2: Multiple manufacturers tested
[ ] RV1-RV3: Manikin ventilation values and deviation from human reference

==============================================================================
SOURCE VERIFICATION SUMMARY
==============================================================================
PRIMARY SOURCES (infant ventilation - IN SCOPE):
- Huang 2016: n=205, PMC4805831 - VERIFIED via direct PDF
- Stoecklin 2024: n=23, J Appl Physiol - VERIFIED via PDF
- Diedericks 2025: FASEB J review - VERIFIED via PDF
- Reiss 2024: n=56 preterm, PMC11748114 - VERIFIED via PDF

PDFS OBTAINED LOCALLY:
- stoecklin_2024_preterm_mechanics.pdf
- reiss_2024_preterm_compliance.pdf
- diedericks_2025_chest_wall.pdf
- huang_2016 (from Proposition repo)

CONTEXT SOURCES (compression - out of scope):
- Japan CC 2024: n=555 - depth targets only, no stiffness
- Babic 2017: confirms evidence gap

==============================================================================
NOTES
==============================================================================
- DR-001 DECIDED: Infant ventilation ONLY
  Rationale: No human stiffness/damping data for infant compression
  -> Cannot benchmark manikin compression without reference values
- All infant ventilation claims (V1-V3) directly verified from source PDFs
- No hallucinations detected in verified claims
- Next: Bronkhorst discussion re airway pressure sensor

Generated by Claude for JV email summary

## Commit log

2026-01-14 Add working folder with reference materials
    - Key compression mechanics articles (Tomlinson, Ruiz de Gauna, Lim)
    - Ventilation mechanics articles (Huang, Battisti)
    - Simulation fidelity theory articles
    - Mechanical fidelity benchmarks reference data
2026-01-14 Add apparatus expansion plan for Engineering Fidelity paper
    Documents required changes to IEEE TIM apparatus:
    Compression:
    - CRITICAL: Add load cell (HX711 + TAL220, ~€65)
    - Mount in series between actuator and compression plate
    - Software: stiffness, damping, Gruben polynomial fitting
    Ventilation:
    - No hardware changes needed
    - Software: add compliance/resistance calculation from existing P/V data
    - Unit conversions (kPa ↔ cmH₂O)
    Estimated timeline: 2 weeks from component arrival
2026-01-14 Update ventilation apparatus requirements with sensor analysis
    - Clarify MFM pressure sensor range (0-17 bar max) may be configurable
    - Add detailed sensor comparison table (MFM vs DPS)
    - Document compliance/resistance calculation methods
    - Add converted Bronkhorst FLEXI-FLOW datasheets and manual
    - Include ventilation mechanics analysis script
2026-01-14 Update README with current status and repository structure
    - Add paper section status table
    - Document working folder structure
    - List datasheets and scripts
2026-01-15 Add literature folder with extracted data from Proposition repo
    - Create input_JV/literature/ folder structure
    - Extract human reference data already verified in Proposition:
    - Adult compression: Lim 2024 (4-10 N/mm), Tomlinson 2007 (non-linear),
    Ruiz de Gauna 2023 (-34.6% dynamic), Neurauter 2009
    - Infant ventilation: Huang 2016 (80-170 mL/kPa)
    - Document evidence gaps MST paper will fill:
    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
2026-01-15 Add core reference PDFs and update literature tracking
    PDFs added (6 papers):
    - lim_2024.pdf - Variable stiffness/damping for CPR manikins
    - tomlinson_2007.pdf - Force-depth relationships in OHCA
    - ruiz_de_gauna_2023.pdf - Dynamic chest stiffness changes
    - neurauter_2009.pdf - Human vs porcine chest comparison
    - huang_2016.pdf - Infant respiratory compliance/resistance
    - battisti_2012.pdf - Neonatal lung compliance
    Updated literature_search.md and backlog.md to reflect
    PDF collection complete for Tier 1 papers.
2026-01-15 Add methodology/modeling papers from respiratory modelling folder
    PDFs added:
    - le_rolle_2008_newborn_lamb.pdf - Newborn lamb respiratory model
    - fresnel_2014_muscle_pressure.pdf - Muscle pressure for mechanical lung
    - athanasiades_2000_nonlinear_lung.pdf - Nonlinear lung model
    Updated literature_search.md with Tier 2 methodology papers
    Identified Babic et al. 2017 (IEEE) for infant CPR manikin testing
2026-01-15 Add recent neonatal papers tracking (2022-2025)
    Created recent_papers_to_obtain.md with DOIs for:
    - Stoecklin 2024: First postsurfactant Crs/CL/Ccw in preterm (HIGH)
    - Japan 2024: Infant CC depth targets (2.7cm at 0mo)
    - SURV1VE Trial 2024: Newborn resuscitation RCT
    - Novel CC technique 2025
    - Reiss 2024: Preterm compliance during CMV
    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
2026-01-15 Verify literature claims C1-C4, V1-V2 and add key source summaries
    Claim registry updates:
    - C1, C2: VERIFIED - Clarified human values (Nysæther 2008) vs manikin range (Lim 2024)
    Human: ~3-11 N/mm stiffness, ~0.17 N·s/mm damping (n=59 OHCA)
    Manikin: 5.34-13.59 N/mm, 0.127-0.511 N·s/mm
    - C3: VERIFIED - Non-linear F-d relationship (Tomlinson 2007, n=91)
    - C4: VERIFIED - 34.6% stiffness decrease (Ruiz de Gauna 2023, n=615)
    - V1, V2: VERIFIED - Infant compliance 78-171 mL/kPa, resistance 3.7-6.4 kPa/L/s (Huang 2016, n=205)
    New article summaries:
    - Nysæther 2008: PRIMARY source for human chest mechanical properties
    - Morin 2024: SAM manikin for ventilation testing, adult C/R reference va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
2026-01-15 Add SURV1VE Trial 2024 and Novel CC Technique 2025
    SURV1VE Trial (PMC11228189):
    - n=27 newborns, CC+SI vs 3:1 ratio
    - Time to ROSC: 90s vs 615s (p=0.0502)
    - Mortality: 18.2% vs 57.1% (NS, small n)
    - Caution: Not for clinical use outside research
    Novel CC Technique (PMC11940949):
    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
2026-01-15 Verify Tier 1 PDFs and update claim registry
    - Verified Lim 2024: Human ref 4-10 N/mm (from Nysæther via [16])
    - Verified Tomlinson 2007: Non-linear relationship, progressivity 1.41±0.25
    - Verified Ruiz de Gauna 2023: 34.6% decrease (95% CI 33.0-36.1)
    - Verified Neurauter 2009: Stiffness 7.7-8.1 N/mm at 50mm (n=30)
    - Added claims C7 (infant compression targets) and V3 (infant Ccw/CL ratio)
    - Coverage: 12/23 claims verified (52%), 11/15 P0 (73%)
    - Updated literature_search.md verification tasks
2026-01-15 Update apparatus plan: Bronkhorst discussion for pressure sensor
    - Added EL-PRESS P-506C (0-100 mbar) as preferred option for airway pressure
    - Keeps calibration chain within Bronkhorst ecosystem (MFM + EL-PRESS)
    - Alternative: MPXV5010DP (~€10) + water column reference
    - Updated backlog with Bronkhorst discussion as priority
    Pending: Discussion with Bronkhorst re: sensor availability
2026-01-15 DR-001 DECIDED: Infant ventilation focus
    Constraints:
    - Only infant manikins available
    - Test equipment suitable for infants only
    Decision: Focus on infant manikin ventilation fidelity
    Rationale:
    - Human reference exists (Huang 2016, n=205): C=78-171 mL/kPa, R=3.7-6.4 kPa/L/s
    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
2026-01-15 MPXV5010GP identified as drop-in replacement for MPXV5050
    - Pin compatible with existing MPXV5050
    - Better resolution: ±0.25 kPa vs ±1.25 kPa (5× improvement)
    - Serves both use cases:
    - C/R characterization: accurate in 0-2 kPa range
    - Blocked airway: saturates at 10 kPa, survives to 40 kPa
    - Still need calibration reference (Bronkhorst or water column)
2026-01-16 Revise DR-001 scope: add infant compression (secondary)
    - Infant ventilation remains primary focus (fidelity index vs Huang 2016)
    - Infant compression added as descriptive characterization (no human reference)
    - Added compression claims RC1-RC3, C5, C7, D3, D4 to registry
    - Confirmed DYMH-103 (0-49N) + HX711 ADC hardware for compression
    - Waiting: calibration weights (HAN lab), Bronkhorst EL-PRESS delivery
2026-01-18 Update lamb protocol: CNC transport to LUMC via trailer
    - Equipment: Transport dedicated CNC to LUMC (home lab setup)
    - IMU (BHI360) demoted to backup option only
    - Added open question: space/power requirements at LUMC
    - Fresh tissue measurement on-site preferred
2026-01-21 Add ventilation measurement apparatus docs and acknowledgements
    - Created hardware/VENTILATION_MEASUREMENT.md with tubing sizes,
    sensor specs (EL-PRESS P-502C, MPXV5010GP, SDP810), and
    T-connector shopping list
    - Added DR-005 acknowledgements registry
    - Updated backlog with load cell calibration results (±0.13 N accuracy)
2026-01-21 Add sensor software and hardware documentation
    EL-PRESS pressure sensor:
    - read_elpress.py: Main reader with CSV output, tare support
    - tare_elpress.py: Zero/tare utility for offset calibration
    - diagnose_elpress.py: Diagnostic tool for debugging
    - README.md: Usage documentation
    Configuration: Port /dev/cu.usbserial-AQ00Z5CQ, node 4
    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
    [Calibration extension for Compression Actuator Load Cell.stl, Compression Actuator extension.stl]
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2026-01-21 Confirm infant chest stiffness gap with Kent/Nysæther sources
    Literature search confirms NO published human infant chest compression
    stiffness (N/mm) data exists:
    - Kent 2010: "No experimental data exist" for pediatric F-D
    - Kent 2009: Youngest data ages 8-22yo (309±55N at 39±5mm, n=18)
    - Kent 2012: PMHS ages 6-7yo (youngest available)
    - Nysæther 2009: Expert consensus reached but N/mm values unpublished
    - Kent 2010: Adult-to-pediatric scaling "did not successfully predict"
    - C5 upgraded to P0: Infant stiffness gap is now critical claim
    - Added C6: Youngest data is 6-7yo (not infant)
    - Added C8: Scaling doesn't work
    - Coverage: 13/21 verified (62%), 7/11 P0 (64%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
2026-01-30 Define model variables and age-dependent Ccw/CL ratios
    - Ventilation model: Compliance (C) + Resistance (R)
    - Compression model: Stiffness (k) + Damping (d)
    - Age-dependent Ccw/CL ratios from Papastamelos 1995:
    Preterm ~5:1 → Term ~3:1 → Infant <1yr ~2.9:1 → Child >1yr ~1.3:1
    - Excluded dynamic softening (adult phenomenon only)
    - Added warning: 15:2 is CPR ratio, not Ccw/CL ratio
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
